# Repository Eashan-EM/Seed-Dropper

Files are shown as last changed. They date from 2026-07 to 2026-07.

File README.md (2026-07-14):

# Seed Dropper

This project creates a drone mount for the S500 Frame, that can be used to drop seeds enclosed within sperical shells

# Components

- 3D printed mount and seeds(max 6)

- SG-90 servo

- S500 frame drone that is setup

- Flysky i6S transmitter

- Any flysky compatible receiver, connected to a pixhawk

- Pixhawk

# Setup

The mount is easy to setup, by just inserting the rods of the drone into the mount

## Setting up the controls

The SG-90 Servo has a 180 degree of possible rotation. By default the servo is positioned at 0 degree. Therefore, the servo can rotate 90 degrees in either side. To control such a movement, there are two possible controls on the transmitter.

- Variable Knob(VRA/VRB)
- 3 way switch

The following procedure uses the variable knob, but the 3 way switch can be easily incorporated

### Transmitter setup

1. Bind the transmitter to the receiver
2. On the transmitter, long press the lock icon for 2 seconds, the lock goes into unlocked state
3. At the top, there will be 2 options, 'function' and 'sys'. The function settigs shouch be selected
4. Scroll down, till 'Aux Channels'
5. Using the left and right arrows, go to any unoccupied channel(anything above channel 4 is good)
6. Click on the icon in the middle(It should be 'none' for unoccupied channel). Then to select vairable knov, click on 'VRx'.
7. By clicking on the right of the icon, either 'VRA' or 'VRB' can be selected
8. Now the variable knob is set to send values on the channel

### Ardupilot Setup

As we're using a pixhawk with Ardupilot software, the configuration must be done using 'Mission Planner'

1. Download the Mission Planner App on desktop
2. Connect the desktop to the pixhawk using a USB cable
3. Open mission planner, and on the top right, click on 'Connect'
> If its not connecting, try setting connection to auto
4. The on the top left, click on 'Setup'
5. Under 'Mandatory Hardware', select 'Radio Calibration'. Make sure the transmitter is also ON
6. Now, try to move the variable knob set. In mission planner that specified channel bar must also move. If the green bar is moving, transmitter is sending signals

### Servo Setup

The pixhawk has two output rails, titled 'Main Out' and 'Aux Out'. The servo must be connected to the 'Aux Out' as they send PWM in 50 Hz.

1. Select any 'Aux Out' rail, e.g. Aux Out 3. Connect your servo to those pins
2. In Mission Planner, goto 'Setup' > 'Mandatory Hardware' > 'Servo Outputs'
3. Select the position that matches with your selected Aux Out
> Positions 1 to 8 are for Main Out 1 to 8. Position 9 onwards correspond to Aux Out. e.g. Position 11 is Aux Out 3
4. Now to set its input as transmitter channel, drop down 'Function'
5. Select 'RCINx', where x is you channel number. e.g RCIN6 equals channel 6
6. Move the variable knob on transmitter, check if servo rotates

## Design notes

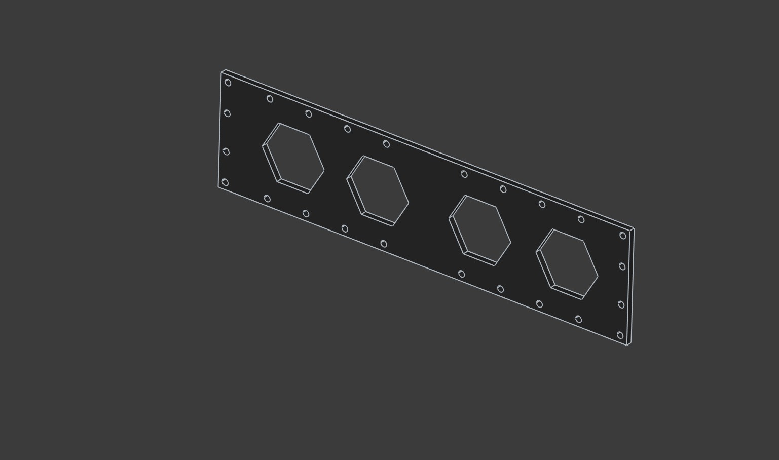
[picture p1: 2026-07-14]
renders/side panel.jpg

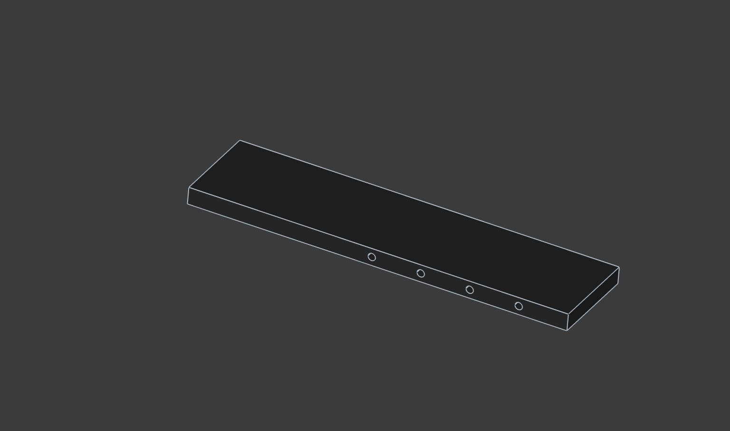
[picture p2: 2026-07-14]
renders/top-bottom plate.jpg

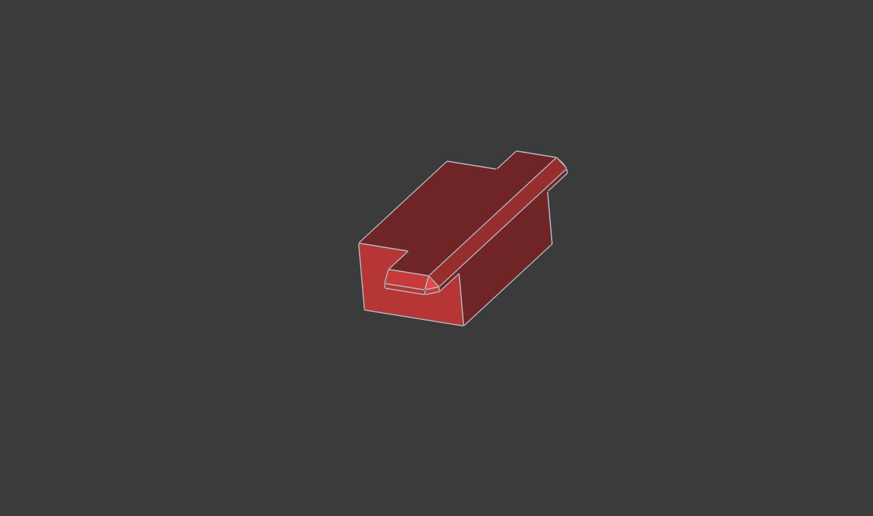
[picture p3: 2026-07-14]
renders/height extender.jpg

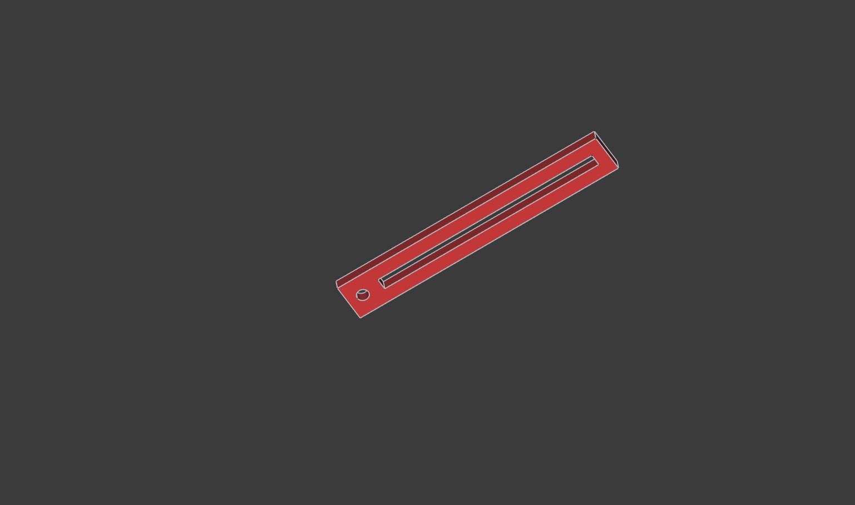
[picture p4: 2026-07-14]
renders/slider.jpg

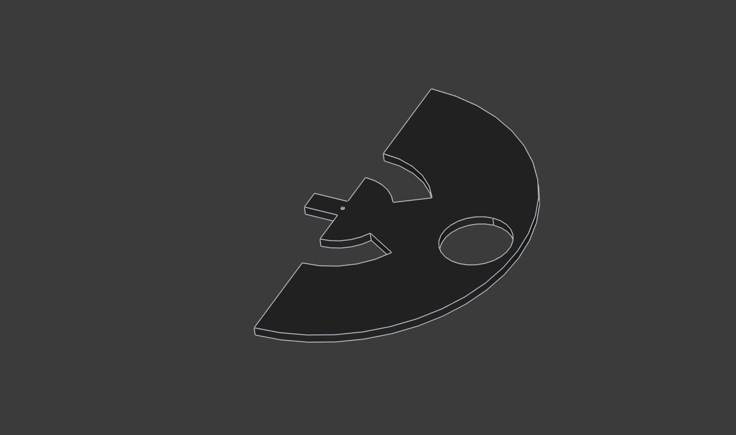
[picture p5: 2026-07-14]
renders/thrower.jpg

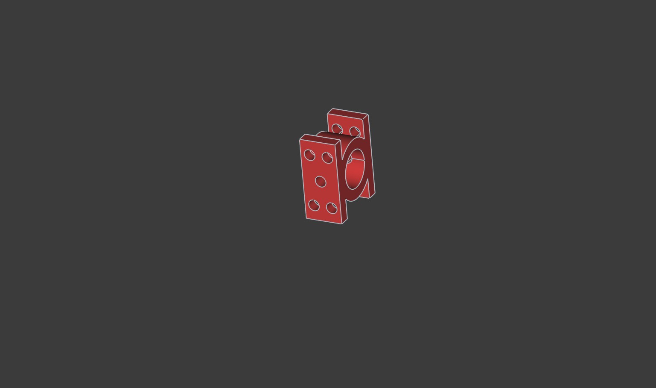
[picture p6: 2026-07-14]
renders/drone mount.jpg

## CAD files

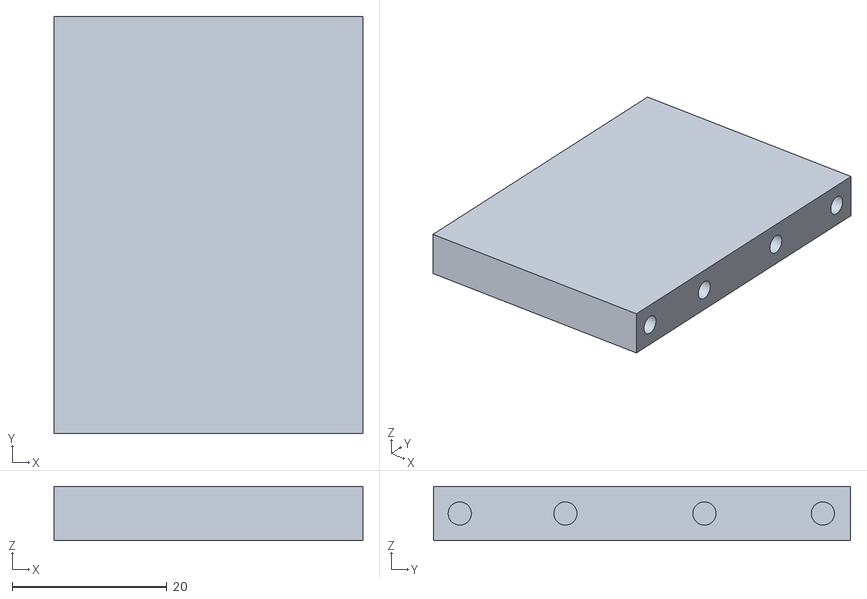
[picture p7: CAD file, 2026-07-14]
exports/front-back panel.stl
40.0 x 54.0 x 7.00

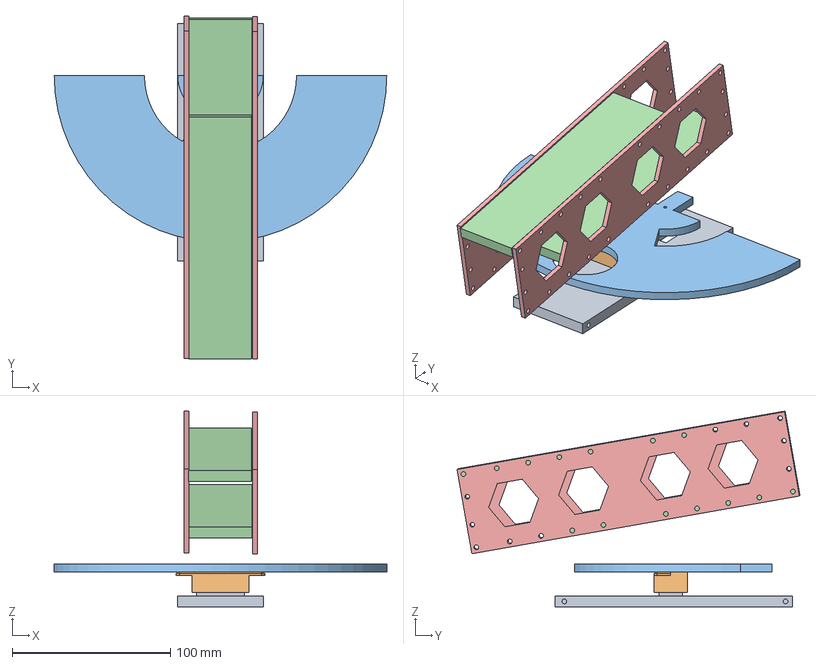
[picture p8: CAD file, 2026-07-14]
freecad/enclosure.FCStd
210.0 x 216.6 x 123.7 mm
stepper holder
height extender
thrower
top-bottom plate x 2
side-panel x 2

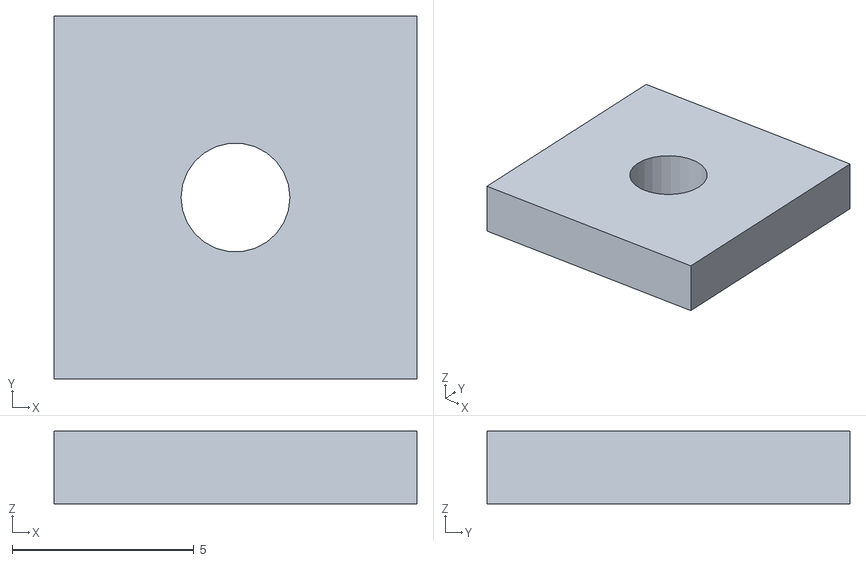
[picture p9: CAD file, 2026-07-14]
exports/friction plate.stl
10.0 x 10.0 x 2.00

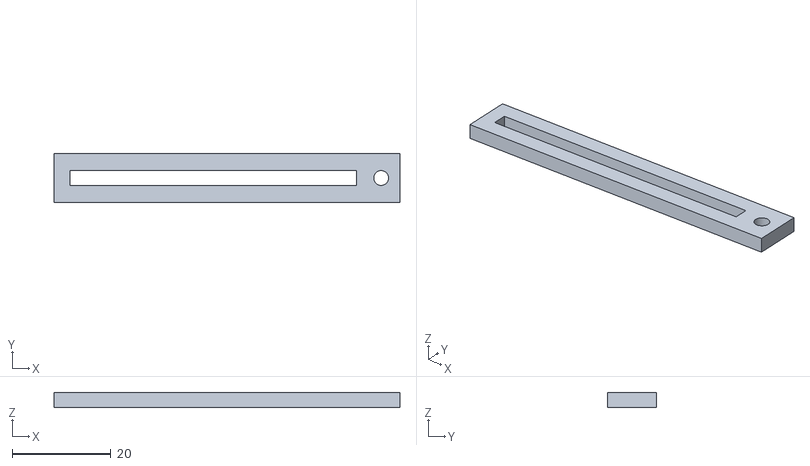
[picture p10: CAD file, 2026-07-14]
exports/slider.stl
70.0 x 10.0 x 3.00

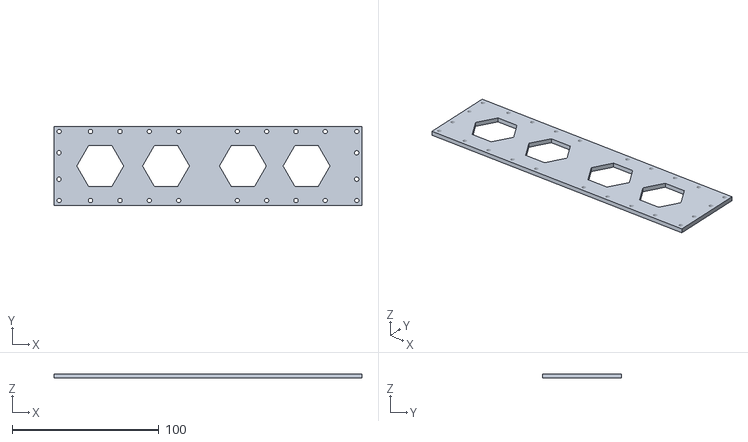
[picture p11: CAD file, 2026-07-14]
exports/side panel.stl
210.0 x 54.0 x 3.00

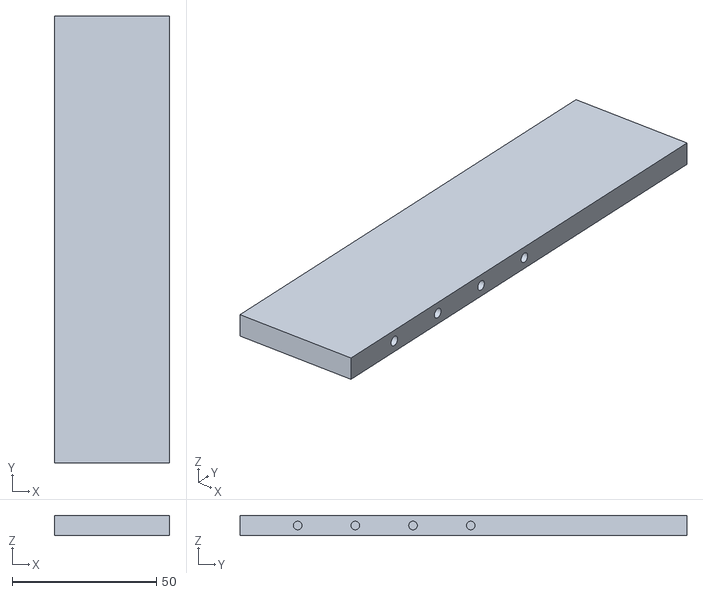
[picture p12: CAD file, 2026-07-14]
exports/top-bottom plate.stl
40.0 x 155.0 x 7.00

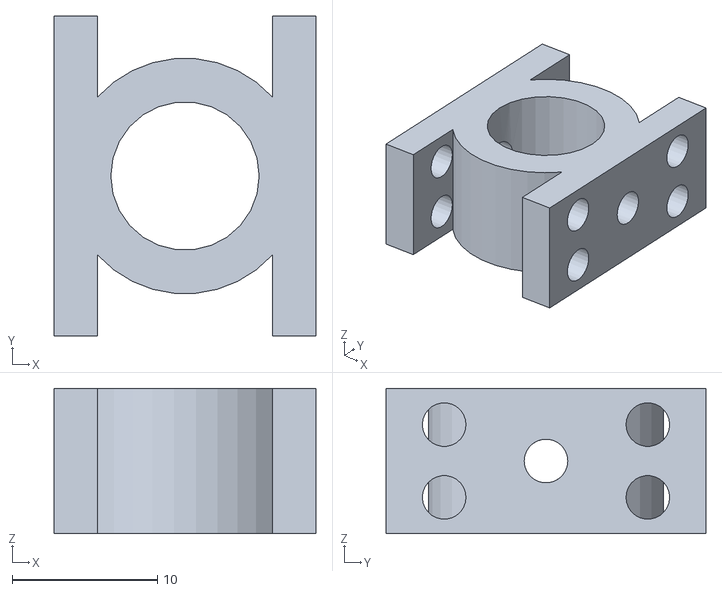
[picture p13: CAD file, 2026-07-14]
exports/drone mount.stl
18.0 x 22.0 x 10.0

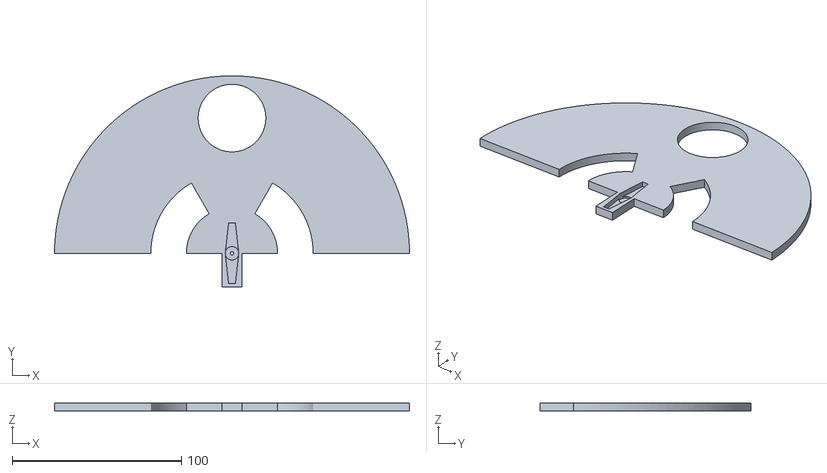
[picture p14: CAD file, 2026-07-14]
exports/thrower.stl
210.0 x 125.0 x 5.00

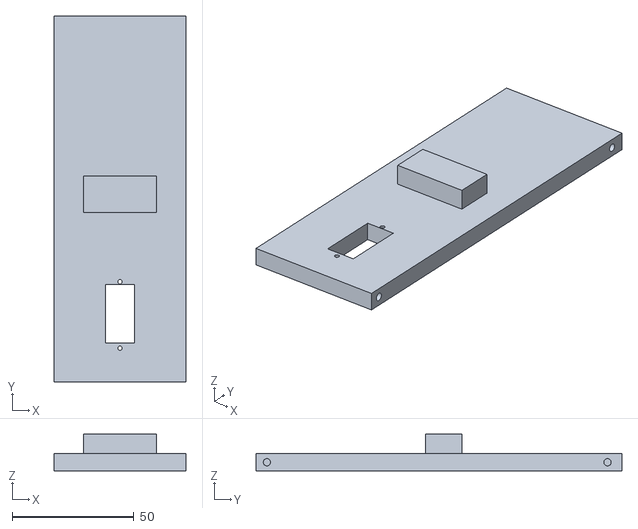
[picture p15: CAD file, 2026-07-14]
exports/stepper holder.stl
54.0 x 150.0 x 15.0

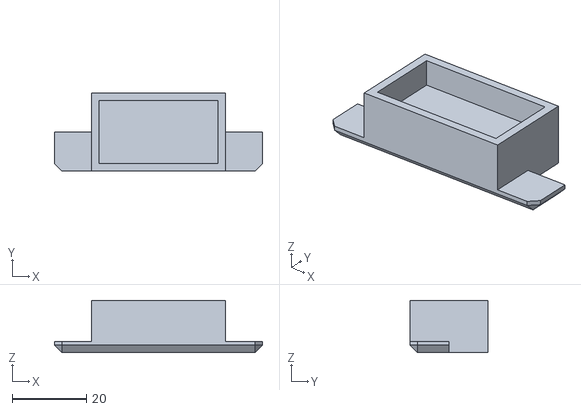
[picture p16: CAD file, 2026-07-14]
exports/height extender.stl
56.0 x 21.0 x 14.0

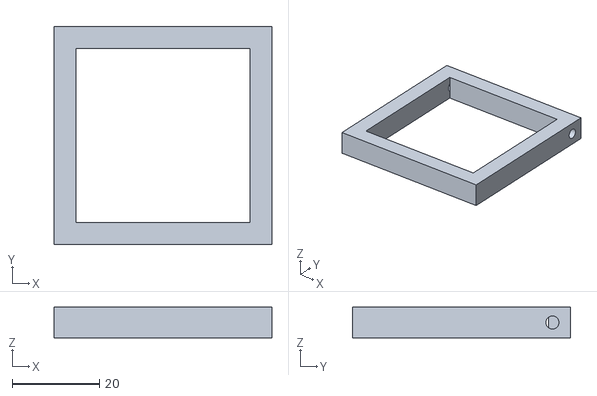
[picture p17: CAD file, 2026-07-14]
exports/height adjuster.stl
50.0 x 50.0 x 7.00

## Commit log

2026-07-14 NEW: Parts for the seed dropper
    [drone mount.stl, enclosure.FCStd, friction plate.stl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]
2026-07-14 NEW: Added README
    [enclosure.FCStd]
